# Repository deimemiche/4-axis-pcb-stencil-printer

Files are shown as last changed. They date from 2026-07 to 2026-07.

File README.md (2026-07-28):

# 4 Axis PCB Stencil Printer w/ Rotational Axis

Stencil printer shown from the top

This is a GitHub mirror/fork of the 4 Axis PCB Stencil Printer
with Rotational Axis by Philipp of [Dengler Mechatronik GmbH](https://dengler-mechatronik.de/).

You can find the source material on:
* [Thingiverse](https://www.thingiverse.com/thing:5690704)
* [Initial announcement](https://dengler-mechatronik.de/?p=560)
* [Digital build log](https://dengler-mechatronik.de/?p=790)

I chose to build this project because of its large working field,
and focus on what really matters - accurate stencil alignment.

All the modifications and their status is described below.

## Mods

### Top plate workholding
This mod adds workholding features (tapped holes) to the top plate,
making adding tooling a breaze.

Technical drawing: [`technical-drawings/top-plate-workholding.dxf`](`top-plate-workholding.dxf`)

Status: in use

### Linear Z axis
Caveat emptor: I never did manage to get the back of the eccenter Z axis working to my satisfaction.
The clamp either captured the threaded rod fully or not at all, not allowing for movement, or rendering
it in raspy freefall over the threads. It is possible I just didn't get it.

What I did manage to get working, however, is a Dremel against a left-over linear rod from a 3D printer,
and hence, the linear Z axis mod was born. It does away with the 2 x 140 mm long M8 threaded rods, and
replaces them with 2 x 140 mm long 8 mm linear rods riding on a bearing mounted to the top frame.
The eccenter mechanism is replaced with the same eccenter used on the front. In order to do that, the 2040
300 mm extrusion is swapped with a 2020 size extrusion of the same length.

Linear Z axis modification, showing linear rods and their mounting

Status: in use

### Hinge locks
The hinges I used still allowed for some play between the back of the frame and the moving part.
Hence the hinge locks were born: if you're looking for repeatability across multiple applies,
or just to increase overall rigidity of the top frame when closed, this is the drop-in addon to print. 

Status: in use

### Bottom plate access holes
This mod replicates the 10 mm access hole seen in the bottom plate in all of five bolt locations.
It allows for easier maintenance and mounting of the threaded rod driven axis as a whole.

Status: in use

## Structure

* [`technical-drawings/`](technical-drawings/) - technical drawings in DXF and PDF formats for CNC manufacturing
* [`cad/`](cad/) - source CAD files, either original author's (STLs), or mine (FreeCAD, CadQuery)
* [`cad/freecad/`](cad/freecad/) - the original author's STLs rebuilt as editable FreeCAD parts, with the tools that measure and check them
* [`docs/`](docs/) - documentation

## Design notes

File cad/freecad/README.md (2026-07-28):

# Parametric reconstructions of the original author's parts

The original author published the printed parts as STL meshes only, so there is
nothing to edit: no sketches, no dimensions, no history. This directory rebuilds
them as FreeCAD **PartDesign** bodies driven by fully constrained sketches, so
any dimension can be changed by double clicking a sketch and typing a new
number.

Each part is a Python script that draws the body, and the `.FCStd` it produces.
The script is the source; the `.FCStd` is a build artefact that is committed so
the parts can be opened without running anything.

## Layout

```
fcprim.py        the helper library every part script is written against
stlmeasure.py    measures the original meshes: layers, outlines, bores
build.py         rebuilds part scripts and reports which ones failed
verify.py        point-samples a built solid against the mesh it came from
stlrender.py     draws a mesh, so a shape can be looked at rather than guessed
export.py        tessellates a built body back to STL, to render against the
                 original

bot/             bottom frame, X and Y axes, rail and rod holders
eccf/            the front eccenter (README calls the mechanism the "eccenter")
sr/              the slewing ring - the rotary alpha axis
top/             top frame, stencil clamp, Z axis
misc/            parts belonging to no one assembly - feet, adapters
plate/           the plates and angles, drawn from the author's own 2D drawings
asm/             the machine itself: the parts put together with real joints
asm/render/      four views of each assembly, drawn by asm/render.py
```

`plate/` is the odd group out. Everything else here is reconstructed from an
STL, because that is all the author published of the printed parts -- but the
aluminium was drawn properly, and `../../technical-drawings/` has those
drawings. So those parts are *transcribed* rather than reverse engineered, and
their check is arithmetic on the drawing's own dimensions rather than a
comparison against a mesh. A mistyped hole position fails the build.

`asm/` is the assembly, built with the Assembly workbench so the machine is held
together by joints and can be driven to any pose rather than frozen in one.
[`ASSEMBLY.md`](ASSEMBLY.md) is the plan and the progress against it.

Every group holds `<part-name>.py` next to the `<PART_NAME>.FCStd` it builds,
named after the STL in [`../`](../) it was reconstructed from.

## Building

FreeCAD 1.1 is needed. With the flatpak:

```sh
alias fc='flatpak run --command=freecadcmd --filesystem=home org.freecad.FreeCAD'

fc cad/freecad/build.py                    # rebuild everything
fc cad/freecad/build.py eccf/eccf-bot.py   # rebuild one part
```

Run from the repository root. `build.py` exists because `freecadcmd` swallows
tracebacks - a script that raises simply prints nothing - so every build goes
through a wrapper that catches and prints them.

## Checking a reconstruction against the original

Two independent checks guard every part.

`build.py` compares the finished solid's volume against the mesh's. Agreement
to a few hundredths of a percent is the faceting error of the mesh's own curved
surfaces, and anything worse fails the build.

Matching volumes are good evidence but not proof, since material moved from one
place to another cancels out. That is not hypothetical: `ECCF_TOP`'s shoulders
were first drawn as plain rectangles because that is what a horizontal slice
through the middle of them looks like. They are really chamfered, and the
chamfer happens to have exactly the same volume as the rectangle - the build
check passed and the part was still wrong.

`verify.py` therefore classifies random points against both shapes -
`isInside` on the solid, ray casting on the mesh - and reports every
disagreement:

```sh
fc cad/freecad/verify.py cad/freecad/eccf/ECCF_BOT.FCStd cad/ECCF_BOT.stl
```

Points within 0.05 mm of a surface are excused, because there the mesh and the
true surface legitimately differ.

## Reading a mesh you want to reconstruct

`stlmeasure.py` runs under plain `python3` - no FreeCAD, no dependencies:

```sh
python3 cad/freecad/stlmeasure.py cad/BOT_RAIL_HOLDER.stl
python3 cad/freecad/stlmeasure.py cad/*.stl --summary
```

Measuring answers "what is there"; a picture answers "what is it". Arc fitting
cannot tell a fillet from a sweep from a draft, and a part whose outline is
nothing but tangent arcs is far quicker to read than to measure:

```sh
python3 cad/freecad/stlrender.py cad/ECCF_LEVER.stl          # four views
python3 cad/freecad/stlrender.py cad/A.stl cad/B.stl out.png # two, overlaid
```

Overlaying a reconstruction on its original is the quickest check there is that
a thread runs the right way round or a profile is not mirrored:

```sh
fc cad/freecad/export.py cad/freecad/sr/SR_WORM_GEAR.FCStd built.stl
python3 cad/freecad/stlrender.py cad/SR_WORM_GEAR.stl built.stl cmp.png
```

Printed parts are layered, so `stlmeasure.py` finds the axis a prism would
explain best,
finds the heights at which the cross section changes, and reports each layer's
outline with the arcs fitted back to centres and radii. It also lists every
cylindrical face about each axis, which is how cross drilled holes are found -
those never show up in the layers.

## Conventions

**Parts are modelled in their mesh's own coordinates.** Several of the STLs were
exported in assembly position rather than about a part origin - the ECCF and SR
groups stack around Y = 0 as they do in the machine. Keeping those coordinates
means the reconstruction can be compared to the mesh directly, and that the
assembly can place most parts without a transform.

**Y is up.** The original author's machine has Y vertical, so parts built along
their print axis are usually sketched on the XZ plane. Note that XZ pads towards
**-Y** while XY pads towards +Z and YZ towards +X; `fcprim.sketch` documents the
full mapping. A sketch normally sits on the part's top face with the pad running
down from it.

**Sketches come out fully constrained.** `fcprim.polyline` works out which
segments are horizontal or vertical, groups the coordinates those constraints
tie together, and adds exactly one dimension per remaining degree of freedom -
no redundancy, whatever mix of straight, slanted and arc segments a profile
uses. `build.py` warns about any sketch that ends up underdefined.

**A 45 degree break that adds material is a tapered pad, not a chamfer.**
`fcprim.pad` takes `taper=45.0`, which drafts the sides as the pad runs; draw
the profile at whichever end of the break is smaller. A `PartDesign::Chamfer`
can only take material away, and it also fails outright where the break has to
die out on a curved face. `STATUS.md` says which parts need which.

**A feature that fails is fatal.** `fcprim.finish` refuses to save if anything
came out `Invalid`, because FreeCAD's own behaviour is to report the throw to
the console, keep the last shape that worked, skip every later feature and hand
back a perfectly valid solid that is missing half the part.

**Constraints are named after what they drive**, so `leg_x1`, `bolt_y_u` and
`nut_across_corners` read sensibly in the Elements panel rather than appearing
as anonymous numbers.

## Notes on individual meshes

* `ECCF_LEVER.stl` contains **two separate shells** - it is a printing pair of
  two identical lever cheeks, not one part.
* `SR_WORM_GEAR.stl` is a helical gear. It is the one part a revolve cannot
  make, and `fcprim.helix` - `PartDesign::AdditiveHelix` - makes it from the
  same kind of fully constrained sketch as everything else.
* `TOP_CLAMP_BEARING_MOUNT_2.stl` is exactly `TOP_CLAMP_BEARING_MOUNT_1.stl`
  mirrored in Z, vertex for vertex. One part script covers both; the assembly
  mirrors it rather than a second body existing.

Several parts come in families, and finding the family is most of the work:

* `BOT_RAIL_HOLDER` and `TOP_RAIL_HOLDER` are the same collar drawn twice - a
  boss around the rail bore, a lobe around each bolt, a fillet rolling along the
  lobes' common tangent, a foot under each bolt. Only the bolt spacing differs,
  and that the bottom one's bore sits 1 mm off the bolt line.
* `BOT_ROD_HOLDER_ALPHA_AXIS`'s first 20 mm are
  `BOT_ROD_HOLDER_ALPHA_AXIS_SHORT` exactly; the rest is the barrel carrying on
  as a 1 degree cone.
* `TOP_CLAMP_SPANNER_CASE_1` and `_2` share an outline exactly.
* `TOP_CLAMP_NUT_HOLDER` and `TOP_CLAMP_SPANNER_COUNTER` share an X/Y footprint
  (X -11.4 .. 5, Y -14.8 .. 15.2) and the same side view - a spine, a block hung
  off it, and the gap between them - so the two run on the same rail.
* `BOT_BEARING_MOUNT_Y_AXIS_DRIVEN` and `BOT_RAIL_CLAMP_X_DRIVE` are hollowed
  from both faces over *identical* spans, with the same two hollow shapes. Once
  the first was drawn the second was mostly a matter of changing the eye's
  position.
* The three 8.2 mm rod clamps - `BOT_CLAMP_Z_AXIS`, `TOP_CLAMP_Z_AXIS` and
  `TOP_CLAMP_STOP` - are all a bore in a 16.2 mm boss with a saw cut and an M3
  pulling it shut.

All 39 meshes are rebuilt, and the 6 drawn parts alongside them, so `build.py`
comes back **45/45**. [`STATUS.md`](STATUS.md) carries the per-part table and
what each awkward one turned out to be; [`ASSEMBLY.md`](ASSEMBLY.md) is the plan
for putting them together into the machine, and how far it has got.

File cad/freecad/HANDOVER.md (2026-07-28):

# Handover: where the assembly stands, and what is wrong with it

Written at the end of a session that got the machine assembling and driving,
and then hit a contradiction it could not settle. This is the state to pick up
from. [`ASSEMBLY.md`](ASSEMBLY.md) is the plan and the reasoning;
[`STATUS.md`](STATUS.md) is the per-part record; this file is only "what is
broken and what was being done about it".

## Read this first: the live bug

**Two independent derivations of the alpha assembly's height disagree by about
5 mm, and the assembly cannot be right until that is settled.**

The alpha axis (the slewing ring and its two plates) rides the Y rails above
the print plate. How high it sits is the one number in `machine.py` that was
never derived, and two parts now claim different answers:

| from | says the plate's underside is at | how |
|---|---|---|
| `BOT_BEARING_MOUNT_Y_AXIS` | **Y = 15.2** | its flange top is 11.6 above its bearing bore, and the bore sits on the Y rail at Y = 3.6 |
| `BOT_RAIL_CLAMP_X_DRIVE` | **Y >= 20.15** | its arm tops out 16.55 above the rail it caps, and reaches *inboard*, under where the plate goes |

15.2 is below 20.15, so the plate would be driven through the cap's arm. One of
these readings is wrong.

### What is solid, and what is not

The **caps are almost certainly right**. `BOT_RAIL_CLAMP_Y_AXIS` is not a
standalone clamp at all -- it is the cap for `BOT_BEARING_MOUNT_X_AXIS`'s
trough, and everything agrees:

    mount cap bolts   x = +-9.0     cap bolts   z = +-9.0     same 18 mm
    mount trough      r = 4.05      cap groove  r = 4.05      same 8 mm rod
    mount house_z     +-10.5 (21)   cap length      21        cap sits on it
    mount width       27            cap width       27
    mount cap_nut_across = 5.7      manual buys 8 Square Nut M3

Four mounts, four caps (2 plain, plus `BOT_RAIL_CLAMP_X_DRIVE` and
`BOT_RAIL_CLAMP_Y_AXIS_1`), 8 x M3x10 = two each. That is manual step 7 exactly,
and `carriage.py`'s `check_caps` confirms each cap's groove lands on its
mount's trough.

So the doubt is on the **other** side. Things worth testing, roughly in order
of how likely they look:

1. **`BOT_BEARING_MOUNT_Y_AXIS` may not mount flange-up.** Its docstring says
   "bolted flat under the frame, with a 15.2 mm bearing seat hanging below it",
   which was written in an earlier session and may be a guess. If it hangs the
   other way the 11.6 becomes something else.
2. **The Y rails may not be at Y = 3.6.** That comes from
   `BOT_BEARING_MOUNT_X_AXIS`'s trough being 14.6 above its own bore, and the X
   rail being at Y = -11. Both are derived, but the X rail's -11 rests on the
   rail holder bolting into the *centre* slot of a 2020's inner face, which is
   assumption not measurement.
3. **The caps' arms may point outboard**, not inboard. That was tried in
   passing: it moves the arm to Z ~ +-144, which then fouls the frame's end
   members at Z = +-130..150. So probably not, but it was not tested properly.
4. **The X drive cap may belong on a different mount** from the one it was
   arbitrarily assigned to (`CAPS` in `carriage.py` assigns them in order).

## What is in the working tree but **not committed**

Last commit is `d21d723`. Everything below is uncommitted and only partly
verified -- decide whether to keep it before building on it.

| file | change | verified? |
|---|---|---|
| `bot/bot-rail-clamp-y-axis.py` | `ROD` + `BOLT1..2` datums | yes, builds, 0.018 % |
| `bot/bot-rail-clamp-y-axis-1.py` | same | yes, builds, 0.019 % |
| `bot/bot-rail-clamp-x-drive.py` | same | yes, builds, 0.018 % |
| `asm/carriage.py` | `rail_caps()`, `check_caps()`, `CAPS` | **yes** -- stage 3 passes |
| `asm/machine.py` | caps placed; `alpha_seat()` now derived from the carriage's own height instead of assumed | **no** |
| `asm/check.py` | new `placed()` helper | **no -- written, never run** |

### The last run, and why it failed

`machine.py` last completed with the alpha plate at **Y = 74.6**, which is
nonsense, and the slewing ring then clashed with the top frame's rails. That
number came from a **real bug that is fixed in the tree but never tested**:

> `App::Link` shares its shape with every other link to the same part, so
> `link.Shape.BoundBox` is the part where it was *drawn*, not where it was put.
> `alpha_seat()` was asking links for their bounding boxes directly and getting
> the wrong answer.

`check.placed()` was added to do this properly and `machine.py` now calls it.
**The very next thing to do is run `machine.py` and see what seat height it
gives.** It should be about 21.2 (the caps' top at 20.15 plus 1 mm). If it is,
the machine will assemble clash-free -- but it will still be sitting at a height
that contradicts `BOT_BEARING_MOUNT_Y_AXIS`, which is the bug above.

Note the same `.Shape` mistake may be lurking elsewhere; `check.solids()` always
handled links correctly, but anything else asking a link for geometry directly
is suspect.

## Everything else that is open

**Four parts exist nowhere** -- no STL, no drawing. Michael has said to leave
them for now:

    TOP_BRACKET   x8   step 12, top frame corners
    ECCB_BODY     x2   step 18, rear eccentric
    ECCB_LEVER    x2
    ECCB_SHIM     x2

**The worm drive is unplaced.** `ALPHA_BOT_PLATE` has a 10 mm hole at r = 75.45
but the ring's teeth are at r ~ 79, so the hole is not where a worm meshing
those teeth would sit. `BOT_ROD_HOLDER_ALPHA_AXIS` holds the worm shaft and its
geometry was never measured -- that is the evidence to go at next, and it should
settle the mesh radius directly.

**The Y bearing spacing is assumed.** `carriage.Y_BEARING_SPACING = 120.0` is a
guess, and it is what limits Y travel to +-25 mm. Closer together gives more.

**`TOP_CLAMP_Z_AXIS` does not verify clean** -- 2 mismatches in 20000 points,
reproducible, predating this work. See `STATUS.md`.

**Manual steps 8 and 9** (lead screws, springs, handwheels) are not built. The
two caps that carry the drives are now placed, which is the groundwork for them.

## What is done and working

All committed, all passing:

* 45 parts build (39 reconstructed from STLs, 6 drawn from the author's 2D
  drawings), `build.py` reports 45/45
* stages 0, 1, 2, 4, 5 and 7 pass; stage 3 passes including the caps
* the machine drives: X +-55, Y +-25, Z 66 mm, alpha +-32.6 deg, with
  interference re-checked at every step of the travel walk
* 32 fasteners placed from the parts' own `BOLT` datums, counts matching the
  manual
* exploded view and renders in `asm/render/`

## Running things

```sh
alias fc='flatpak run --command=freecadcmd --filesystem=home org.freecad.FreeCAD'

fc cad/freecad/build.py                 # all 45 parts
fc cad/freecad/asm/stage0.py            # the regression test for joints
fc cad/freecad/asm/frame.py             # stage 1
fc cad/freecad/asm/carriage.py          # stage 3
fc cad/freecad/asm/alpha.py             # stage 4
fc cad/freecad/asm/column.py            # stage 5
fc cad/freecad/asm/machine.py           # stage 7, the whole thing
fc cad/freecad/asm/render.py            # redraw everything
python3 cad/freecad/asm/reference.py    # fetch the author's step images
```

`machine.py` takes a few minutes -- the travel walk runs an interference pass
per step. `freecadcmd` prints **nothing at all** for an uncaught exception, so a
silent run means a crash, not success; `build.py` and `render.py` wrap
themselves to print tracebacks, and anything new should too.

Two flags worth knowing: `freecadcmd` swallows script arguments unless they come
after `--pass`, and it sets `__name__` to the module's basename rather than
`"__main__"`, which is why the stage scripts guard on `asmprim.is_entry()`.

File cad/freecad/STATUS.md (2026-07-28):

# Reconstruction status

## Mapping and gaps: mesh, model, manual

Three sets that ought to agree and do not quite: the STLs the author
published, the FreeCAD parts here, and the parts his assembly manual actually
calls for.

| | count |
|---|---|
| STLs in [`../`](../) | 39 |
| reconstructed from an STL | **39** -- every one, no orphans |
| FreeCAD parts with no STL | 6, the `plate/` group, drawn from his 2D drawings |
| **parts the manual needs that exist nowhere** | **4** |
| total parts built | 45 |

### The four that are missing

Nothing to reconstruct from and no drawing either, so these cannot be modelled
without either the author publishing them or somebody drawing them from
scratch:

| Part | Manual | Needed |
|---|---|---|
| `TOP_BRACKET` | step 12, top frame corners | x8 |
| `ECCB_BODY` | step 18, **rear** eccentric | x2 |
| `ECCB_LEVER` | step 18 | x2 |
| `ECCB_SHIM` | step 18 | x2 |

The front eccentric (`ECCF_*`) is published in full; the rear one is not. So
the machine can be assembled up to the top frame and no further. This is what
blocks stage 6, and half of what the top frame needs in stage 5.

### Names the manual and the meshes disagree on

Worth writing down, because each one looks like a missing part until it is
chased:

| the manual says | the mesh is called |
|---|---|
| `BOT_CLAMP_Z` | `BOT_CLAMP_Z_AXIS` |
| `BOT_TAIL_CLAMP_Y_AXIS_1` | `BOT_RAIL_CLAMP_Y_AXIS_1` (its typo) |
| `TOP_BEARING_MOUNT_1` / `_2` | `TOP_CLAMP_BEARING_MOUNT_1` / `_2` |
| `TOP_CLAMP_SPANNER_CASE` | `TOP_CLAMP_SPANNER_CASE_1` |
| `Adapter D5 to M3x14` | `ADAPTER_D5_TO_M3` |

### Assembly datums: 5 of 45

The gap that governs how much of the assembly is left. A part can only be
*joined* once it carries named datums (`fcprim.lcs`), and only the parts the
built stages actually join have them:

| Part | Datums |
|---|---|
| `BOT_RAIL_HOLDER` | `RAIL`, `MOUNT`, `BOLT1..2` |
| `BOT_BEARING_MOUNT_X_AXIS` | `RAIL`, `TROUGH`, `PLATE`, `BOLT1..4` |
| `BOT_CLAMP_Z_AXIS` | `ROD`, `MOUNT` |
| `TOP_CLAMP_Z_AXIS` | `ROD`, `MOUNT` |
| `TOP_RAIL_HOLDER` | `RAIL`, `MOUNT`, `BOLT1..2` |

The other 40 are reconstructed and checked but not yet joinable. That is by
design -- datums get added as the stage that needs them arrives, so they are
placed against a real mating requirement rather than guessed at.

### One inconsistency, harmless so far

`bot/bot-right-angle-con.py` builds through `fcprim.document` and
`fcprim.finish` directly instead of `fcprim.make`, so it skips
`check_sketches` and would not warn about an underdefined sketch. Checked by
hand: all four of its sketches are fully constrained, so nothing is hiding
behind it. Worth tidying, not worth hurrying.

## The parts that were drawn, not reverse engineered

The author published the aluminium as proper 2D drawings rather than as meshes,
so these six are transcribed from [`../../technical-drawings/`](../../technical-drawings/)
instead of measured off an STL. There is no mesh to compare against and none is
wanted: the check is that the finished solid's volume matches arithmetic on the
drawing's own dimensions, so a mistyped hole position fails the build.

| Part | Drawing | Size mm | Notes |
|---|---|---|---|
| `XY_PLATE` | `base-plate.dxf` | 257 x 162 x 2 | 16 x 3.2, at x +-97.65 / +-124.35, z +-59 / +-76 |
| `ALPHA_BOT_PLATE` | `bottom-plate.pdf` | 200 x 200 x 6 | 4 x M3 on a 122 bolt circle, 10 for the worm at x 75.45, 24 x M3 in clusters |
| `ALPHA_TOP_PLATE` | `top-plate-workholding.dxf` | 240 x 200 x 6 | 5 x M3 at r 75.45, plus an 83 hole staggered grid |
| `ALPHA_TOP_PLATE_PLAIN` | `top-plate-plain.dxf` | 240 x 200 x 6 | the same plate before the grid is drilled |
| `STENCIL_HOLDER_BOT` | `stencil-holder-bottom.pdf` | L 20x20x2, 198 | 4 x 5 at +-25 / +-75, one 5.4 through the upright |
| `STENCIL_HOLDER_TOP` | `stencil-holder-top.pdf` | L 20x20x2, 213.72 | 6 + 2 x 5, two 5.4; across-leg positions are the least certain thing here |

Two things fell out of doing these that were not obvious from the build page.
The alpha axis has **two** plates, a fixed 200 x 200 and a rotating 240 x 200,
which is why the page's "200 x 200 x 6" and the drawings' 240 x 200 looked like
a contradiction. And `ALPHA_TOP_PLATE`'s grid comes to exactly the 83 holes its
drawing annotates, which is a real check on having read the stagger right --
the script refuses to build if it does not.

## The reconstructed meshes

One row per mesh in [`../`](../). "Prismatic" is the fraction of the mesh's
surface area that a prism along the listed axis explains: 1.00 is a pure
extrusion, and the shortfall is chamfers, blends, cross drilled holes and
anything turned or helical. It is a fair proxy for how much work a part is.

Rebuilding a part means: measure it with `stlmeasure.py`, write the script,
then get both checks in [`README.md`](README.md) to pass - volume within the
mesh's own faceting error, and zero point classification mismatches.

**All 39 done.** Every script builds.

The claim that every one passes `verify.py` with **zero** mismatches does not
quite hold, and it is worth being exact rather than tidy about it.
`TOP_CLAMP_Z_AXIS` reports **2 mismatches out of 20000 sample points**, with 3
more excused inside the 0.05 mm skin. It is reproducible -- the sampler seeds
deterministically, so the same two points disagree every run -- and it is not
a regression: adding datums does not touch a body's shape, and the part's
volume reads the same before and after.

Two points in twenty thousand is a very small discrepancy, most likely one
detail of the saw cut or a break that is slightly off, and nothing built on
this part has shown it. But it is not zero, and the four other parts checked
alongside it (`BOT_RAIL_HOLDER`, `BOT_BEARING_MOUNT_X_AXIS`,
`BOT_CLAMP_Z_AXIS`, `TOP_RAIL_HOLDER`) do report a clean match, so the
difference is real rather than a quirk of the checker.

The remaining 34 have not been re-run recently -- `verify.py` takes a few
minutes a part -- so "all 39 pass" should be read as "all 39 passed when they
were written, and one of the five re-checked since does not". The worst volume deviation is 0.26 %, on `SR_WORM_GEAR`, and that is
the original mesh's own faceting error on a helical surface; the next worst is
0.054 %.

| Part | Size mm | Volume mm3 | Axis | Prismatic | Status |
|---|---|---|---|---|---|
| `ADAPTER_D5_TO_M3` | 6.4 x 3.5 x 6.4 | 52 | Y | 0.94 | **done** `misc/` |
| `BOT_BEARING_MOUNT_X_AXIS` | 27.0 x 26.2 x 35.0 | 10098 | X | 0.85 | **done** `bot/` |
| `BOT_BEARING_MOUNT_Y_AXIS` | 27.0 x 18.0 x 38.0 | 6369 | X | 0.94 | **done** `bot/` |
| `BOT_BEARING_MOUNT_Y_AXIS_DRIVEN` | 27.0 x 18.0 x 49.9 | 9014 | X | 0.96 | **done** `bot/` |
| `BOT_BRACKETS` | 60.0 x 4.0 x 60.0 | 8118 | Y | 1.00 | **done** `bot/` |
| `BOT_BRACKET_X_AXIS` | 36.0 x 19.8 x 60.0 | 9746 | X | 0.91 | **done** `bot/` |
| `BOT_CLAMP_Z_AXIS` | 31.8 x 40.0 x 17.2 | 10794 | Y | 0.86 | **done** `bot/` |
| `BOT_HANDWHEEL` | 30.0 x 26.0 x 29.4 | 10725 | Y | 0.81 | **done** `bot/` |
| `BOT_RAIL_CLAMP_X_DRIVE` | 43.9 x 16.5 x 27.0 | 8418 | Z | 0.83 | **done** `bot/` |
| `BOT_RAIL_CLAMP_Y_AXIS` | 21.0 x 7.0 x 27.0 | 3145 | X | 0.89 | **done** `bot/` |
| `BOT_RAIL_CLAMP_Y_AXIS_1` | 49.1 x 11.3 x 45.1 | 9094 | X | 0.83 | **done** `bot/` |
| `BOT_RAIL_HOLDER` | 11.4 x 16.0 x 28.6 | 2288 | X | 0.94 | **done** `bot/` |
| `BOT_RIGHT_ANGLE_CON` | 21.0 x 20.0 x 20.0 | 3861 | Z | 0.95 | **done** `bot/` |
| `BOT_ROD_HOLDER_ALPHA_AXIS` | 68.6 x 12.2 x 28.3 | 6310 | X | 0.62 | **done** `bot/` |
| `BOT_ROD_HOLDER_ALPHA_AXIS_SHORT` | 20.0 x 12.2 x 28.3 | 3204 | X | 0.93 | **done** `bot/` |
| `BOT_Z_AXIS_COUNTER_HOLDER` | 40.0 x 24.0 x 20.0 | 6349 | Y | 0.88 | **done** `bot/` |
| `BOT_Z_AXIS_COUNTER_KNOB` | 24.0 x 17.0 x 23.7 | 4762 | Y | 0.80 | **done** `bot/` |
| `ECCF_BOT` | 40.0 x 8.0 x 20.0 | 4961 | Y | 1.00 | **done** `eccf/` |
| `ECCF_HEIGHT` | 44.0 x 10.0 x 43.4 | 10162 | Y | 1.00 | **done** `eccf/` |
| `ECCF_LEVER` | 34.4 x 29.3 x 45.8 | 4929 | X | 0.74 | **done** `eccf/` |
| `ECCF_MOUNT` | 26.4 x 14.0 x 26.4 | 3888 | Y | 0.74 | **done** `eccf/` |
| `ECCF_TOP` | 44.0 x 27.0 x 26.4 | 13649 | Y | 0.89 | **done** `eccf/` |
| `SR_BEARING_PLATE` | 130.0 x 3.0 x 130.0 | 4887 | Y | 0.94 | **done** `sr/` |
| `SR_INNER_RING` | 140.0 x 10.0 x 140.0 | 12887 | Y | 0.63 | **done** `sr/` |
| `SR_OUTER_RING_W_GEAR` | 154.0 x 12.0 x 160.6 | 38024 | Y | 1.00 | **done** `sr/` |
| `SR_WORM_GEAR` | 10.0 x 20.0 x 10.0 | 754 | Y | 0.32 | **done** `sr/` |
| `STAND` | 11.5 x 7.0 x 11.5 | 373 | Y | 0.62 | **done** `misc/` |
| `TOP_CLAMP_BEARING_MOUNT_1` | 26.0 x 27.0 x 21.0 | 7142 | X | 0.94 | **done** `top/` |
| `TOP_CLAMP_BEARING_MOUNT_2` | 26.0 x 27.0 x 21.0 | 7142 | X | 0.94 | **done** `top/` |
| `TOP_CLAMP_NUT_HOLDER` | 16.4 x 30.0 x 14.0 | 4127 | Y | 0.90 | **done** `top/` |
| `TOP_CLAMP_SPANNER_CASE_1` | 3.2 x 14.0 x 58.0 | 1782 | X | 0.93 | **done** `top/` |
| `TOP_CLAMP_SPANNER_CASE_2` | 9.0 x 14.0 x 58.0 | 3572 | X | 0.96 | **done** `top/` |
| `TOP_CLAMP_SPANNER_COUNTER` | 16.4 x 30.0 x 58.0 | 19315 | Z | 0.94 | **done** `top/` |
| `TOP_CLAMP_SPANNER_HANDWHEEL` | 5.0 x 33.8 x 34.0 | 3111 | X | 0.99 | **done** `top/` |
| `TOP_CLAMP_STOP` | 10.0 x 20.8 x 15.6 | 1750 | X | 0.88 | **done** `top/` |
| `TOP_CLAMP_Z_AXIS` | 30.2 x 34.0 x 32.0 | 10387 | Y | 0.86 | **done** `top/` |
| `TOP_HANDWHEEL_Z_AXIS` | 38.0 x 17.0 x 37.5 | 11108 | Y | 0.91 | **done** `top/` |
| `TOP_RAIL_HOLDER` | 11.4 x 16.1 x 27.6 | 2166 | X | 0.91 | **done** `top/` |
| `TOP_SPRING_PLATE` | 19.4 x 4.4 x 19.4 | 769 | Y | 0.81 | **done** `top/` |

## The gusset that looked like a free-form blend

`BOT_RAIL_CLAMP_Y_AXIS_1` held out longest, and only because it was measured
the wrong way. Fitting arcs to its sections gave radii that changed with height,
which reads as a doubly curved surface and is exactly what a **torus** does: a
section of one is not a circle. Its outer surface is a 33.5 mm arc turned about
the tube's own axis, and two of the part's dimensions fall out of that arc
rather than being chosen - it reaches furthest out where the clamp block ends,
and it lands on the tube's own diameter where the part stops.

The flanks looked worse still: ruled, but neither plane, cylinder nor cone. They
are simply the two lines tangent to the tube **from the block's own front
corners**, rounded into those corners on 10 mm. Once that is seen the whole
gusset is one prism and one revolved cut.

The lesson is the same one `stlrender.py` teaches: measure a section and you get
numbers that fit many shapes; ask what construction would put a surface there
and usually only one answer survives.

## Shapes that turned up more than once

Recognising these cut the work on the second and third instance to almost
nothing, so they are worth looking for first.

* **Rail holders** (`BOT_RAIL_HOLDER`, `TOP_RAIL_HOLDER`) are twins, and
  `BOT_ROD_HOLDER_ALPHA_AXIS`'s first 20 mm are
  `BOT_ROD_HOLDER_ALPHA_AXIS_SHORT`.
* **`TOP_CLAMP_BEARING_MOUNT_2`** is exactly `..._1` mirrored in Z, vertex for
  vertex. `top-clamp-bearing-mount-2.py` runs the other script for its builder
  rather than repeating it.
* **The webbed arm.** `BOT_BEARING_MOUNT_Y_AXIS_DRIVEN` and
  `BOT_RAIL_CLAMP_X_DRIVE` are hollowed from both faces over *identical* spans -
  a 2 mm skin at each end and one 2 mm rib, at -13.5/-11.5, -9.5, 5.1/7.1,
  11.5/13.5. Both use the same two hollow shapes: a half round of radius 5.5
  about the eye between the ribs, and beside each skin the same idea drawn to a
  smaller radius and roofed with a 120 degree vee so it prints unsupported.
* **Knurled knobs** (`BOT_HANDWHEEL`, `BOT_Z_AXIS_COUNTER_KNOB`,
  `TOP_HANDWHEEL_Z_AXIS`, `ECCF_HEIGHT`) are all one turned section, one flute
  pocket and a polar pattern.
* **The 8.2 mm rod clamp** - bore 8.2 in a 16.2 boss, saw cut, M3 pulling it
  shut - is `BOT_CLAMP_Z_AXIS`, `TOP_CLAMP_Z_AXIS` and `TOP_CLAMP_STOP`.

## Look at the part

Everything here was measured before it was ever seen, and for prismatic parts
that is the better way round - an arc fitted to a section is worth more than a
picture. For the last few it was the wrong way round. `stlrender.py` draws a
mesh from four orthographic views; `ECCF_LEVER` had been sitting in the "hard,
organically blended" pile and turned out, on sight, to be a flat plate with an
eye at each end and a waisted arm between - an afternoon's guesswork replaced by
one glance.

It also checks work. `export.py` tessellates a built body back to STL, and
rendering the two together in different colours settles at a glance what a
volume figure cannot: whether a thread runs the right way round.

    python3 cad/freecad/stlrender.py cad/ECCF_LEVER.stl
    fc cad/freecad/export.py cad/freecad/sr/SR_WORM_GEAR.FCStd built.stl
    python3 cad/freecad/stlrender.py cad/SR_WORM_GEAR.stl built.stl cmp.png

## The one thing a revolve cannot do

`SR_WORM_GEAR` is a helix, and a helix advances along its axis as it turns.
`fcprim.helix` wraps `PartDesign::AdditiveHelix`, which sweeps a sketched
profile along one and wants exactly the same fully constrained sketch as
everything else - so the worm is a bored tube plus one trapezium, and not the
mesh it was assumed it would have to stay.

Two things about it are worth knowing. The thread starts and stops at the part's
own ends rather than running past them, so its first and last turn are only
partly there; running the sweep long and trimming instead puts 10 mm3 too much
material in. And `Mode` takes `"pitch-height-angle"` in lower case - the string
FreeCAD shows in the GUI is rejected.

## Chamfers that add material, and where dressups give up

A 45 degree break is a `PartDesign::Chamfer` only when it takes material away
from an edge that already exists. Two cases here are neither:

* **A break at the foot of a boss adds material** - `BOT_HANDWHEEL`'s lug is
  1 mm wider where it stands on the rim, and `BOT_CLAMP_Z_AXIS` stands on two
  ribs that flare out where they meet its underside. No dressup can do that.
* **A break that dies out on a curved surface** makes OCC fail outright:
  `BOT_HANDWHEEL`'s lug is broken 1 mm round its top, and that break runs out
  where the outline crosses the collar. `BRep_API: command not done`.

Both are drawn instead as a `Pad` with `taper=45.0`, which drafts the sides as
the pad runs. Draw the profile at whichever end of the break is *smaller* and
let the taper open it out. Where the tapered face must not appear on every side
of the profile - `BOT_CLAMP_Z_AXIS`'s ribs run the full width without a flare on
their ends - draw the trapezium in section and pad it the other way instead.

A dressup is still the right answer where the break follows something no single
sketch contains: both handwheels and the counter knob are broken 1 mm round the
rim, and that break follows the grip flutes as well, so it has to be taken after
the flutes are cut.

## A feature that fails is not an error

`fcprim.finish` now refuses to save if any feature came out `Invalid`. Without
that check a throwing feature is only reported to the console: the body keeps
the last shape that worked, **every later feature is silently skipped**, and the
result is still a valid solid. A failed chamfer on `BOT_HANDWHEEL` swallowed the
bore and two pockets after it and still built.

## Fillets that are surfaces, not extrusions

Where a boss stands on a plate, the fillet round its root runs along a curved
edge that no single sketch contains. `PartDesign::Fillet` is the obvious answer
and it does not work here: on `BOT_Z_AXIS_COUNTER_HOLDER` the boss also blends
into the plate's long edges tangentially, and a fillet that has to terminate on
a tangent surface junction fails outright - at any radius, one edge at a time or
all of them.

What does work is to draw the fillet in section, revolve it all the way round,
and pocket back the part of the ring that has no plate under it. Three sketched
features instead of one dressup, every dimension named, and nothing depends on
an edge number that moves when an earlier sketch changes.

Beware `Shape.BoundBox` after a revolve: it bounds the surfaces' control hulls,
not the solid, and read 0.9 mm too wide on that part. Point sampling said there
was nothing there, and there was not.

## Two ways the layer scan lies

Both cost an afternoon before they were understood, so they are worth stating
plainly. Neither shows up as a bad volume, which is why `verify.py` exists.

**A layer boundary is not always a real step.** `levels()` finds heights where
facets face along the build axis, and a cross drilled hole's cylinder has such
facets where it is tangent to the cutting plane. `BOT_ROD_HOLDER_ALPHA_AXIS_SHORT`
appears to have three layers and really has one: the two inner boundaries are
where its M3 holes turn over. `BOT_BEARING_MOUNT_X_AXIS` scans as a step at
X = +/-6.703 and that is only where its 3.6 mm bolt holes turn over. Worse, a
section taken through such a hole is cut into several loops that look like
separate bodies - `TOP_CLAMP_STOP` sections as three pieces at every height, and
is one.

**A real step does not always show up as a layer.** Anything sloped has no
facet facing along the axis at all. `TOP_CLAMP_STOP` scans as a clean prism
along X and its tongue has a 3 mm chamfer off both far corners;
`BOT_BRACKET_X_AXIS` scans the same way and its plate's inside corner is a
22.5 mm sweep. A prismatic score below about 0.95 means at least one such
surface is there to be found.

## When the volume is out, compare sections rather than guessing

Volume is one number and says nothing about where the material is. Slicing both
the mesh and the built solid at the same run of heights and differencing the
areas localises the error immediately, and the *shape* of the difference names
it: a constant offset is a missing prism, a smooth curve is a missing round.

`BOT_RAIL_CLAMP_X_DRIVE` was 13.8 % over. The section scan showed the error was
zero outside one span, so the outline and every hole were right; inside that
span the difference was a smooth symmetric curve, which turned out to be an
unmodelled tapered channel up the underside, plus a flat 32.9 mm2 that was a
half round drawn with its arcs bulging the wrong way.

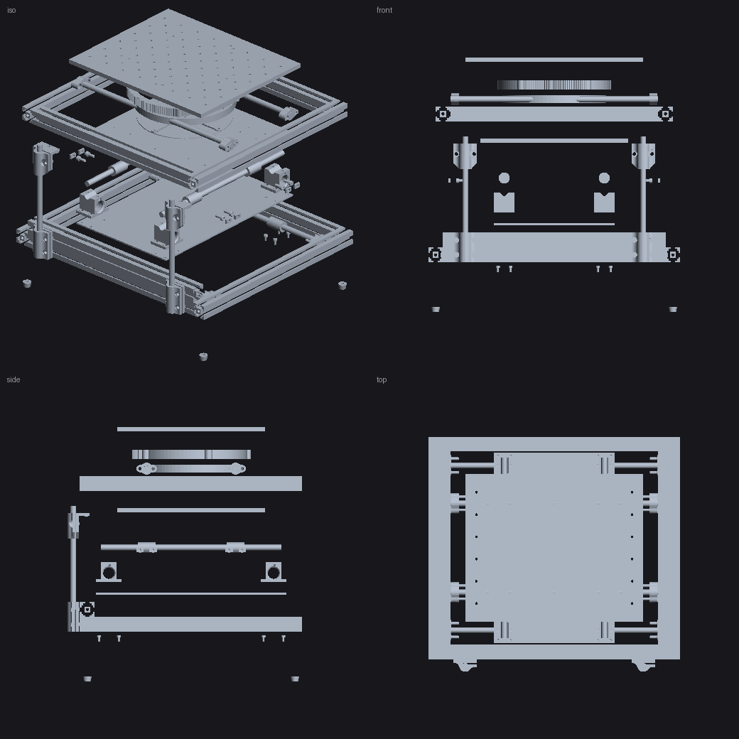
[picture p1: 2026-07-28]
cad/freecad/asm/render/MachineExploded.png

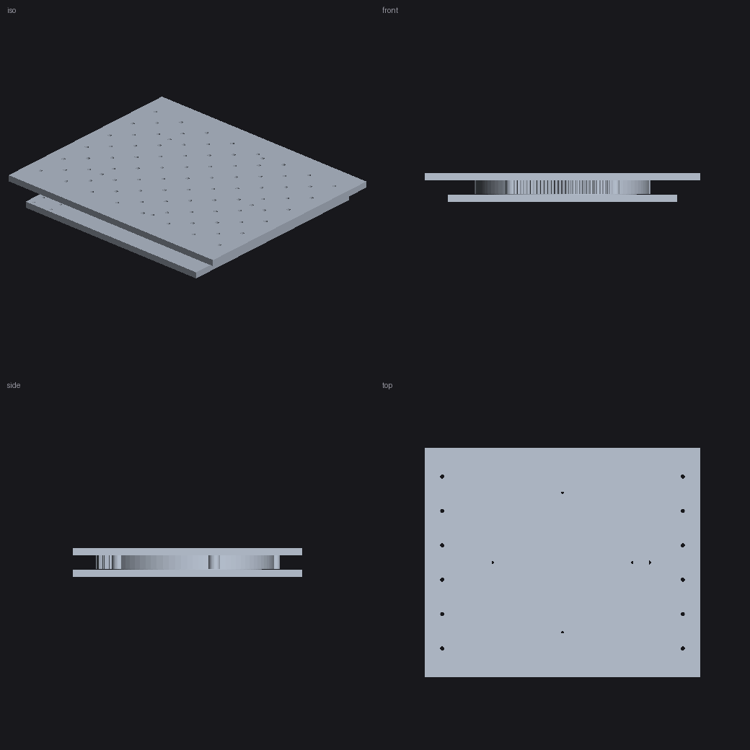
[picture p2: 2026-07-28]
cad/freecad/asm/render/Alpha.png

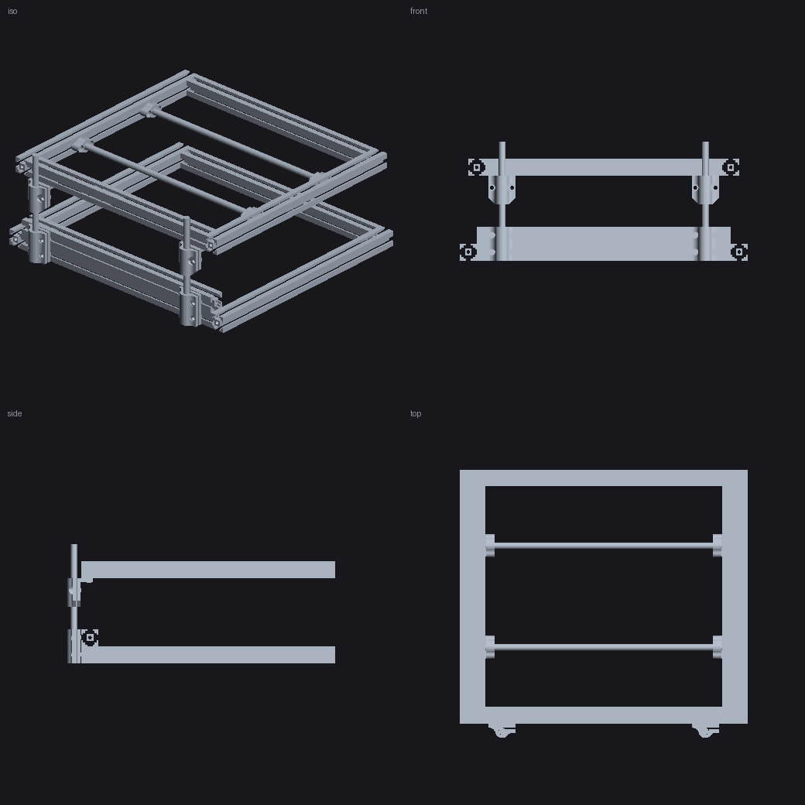
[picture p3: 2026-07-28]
cad/freecad/asm/render/Column.png

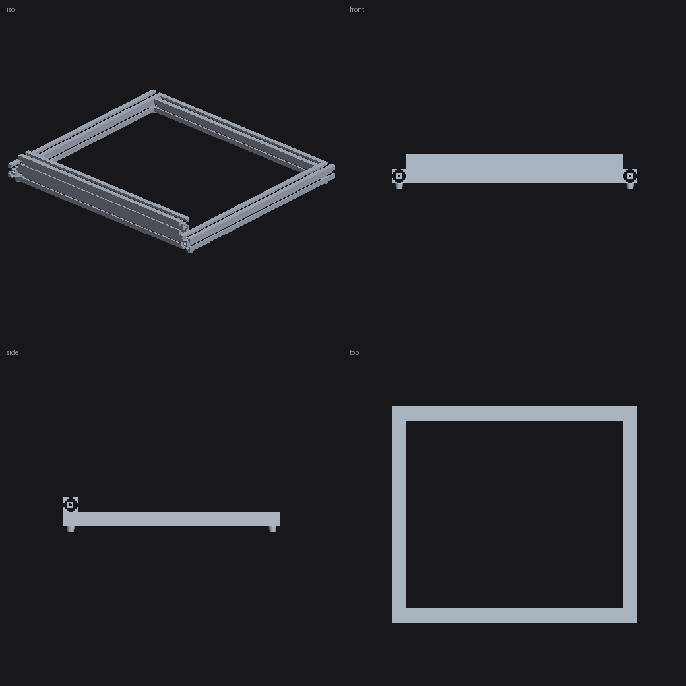
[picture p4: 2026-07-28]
cad/freecad/asm/render/BottomFrame.png

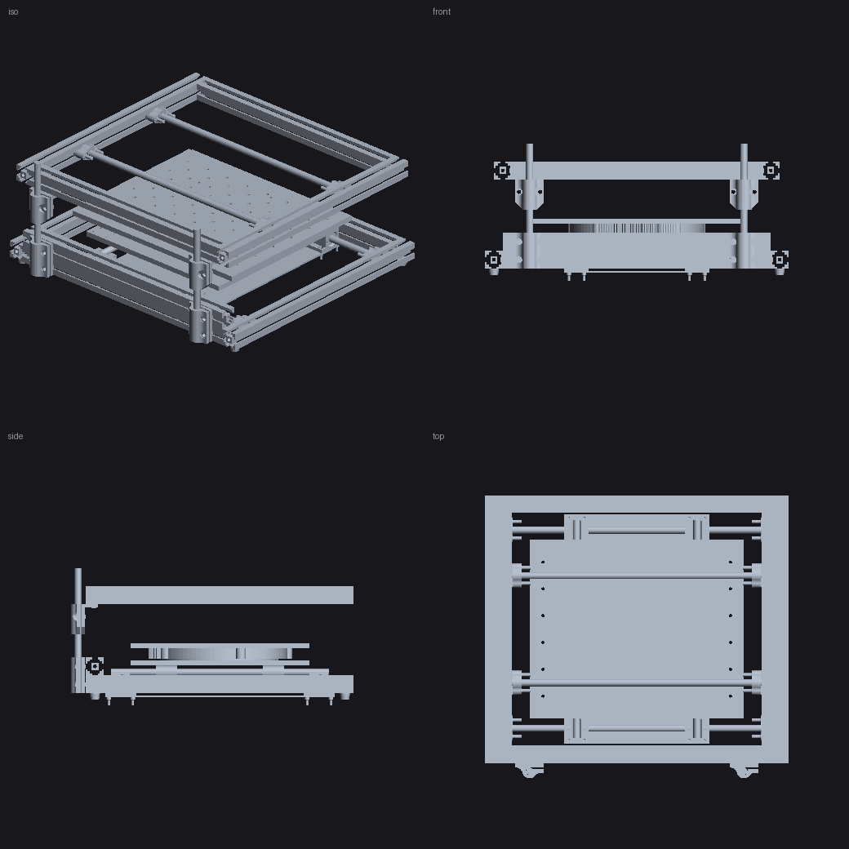
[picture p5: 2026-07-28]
cad/freecad/asm/render/Machine.png

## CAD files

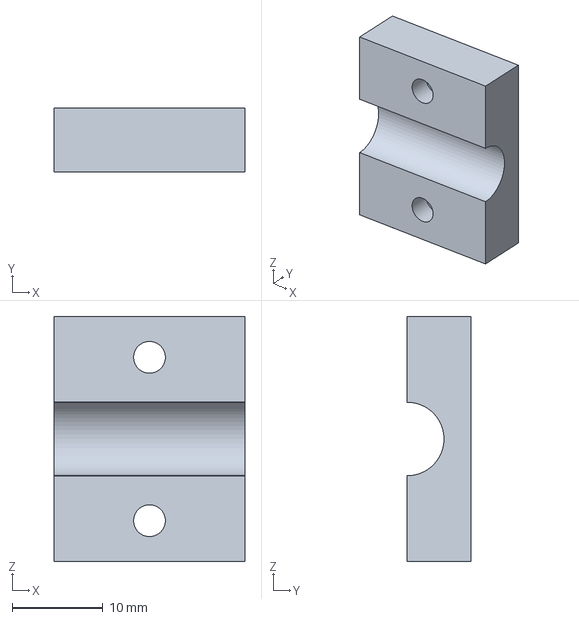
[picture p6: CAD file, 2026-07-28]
cad/freecad/bot/BOT_RAIL_CLAMP_Y_AXIS.FCStd
21.0 x 7.00 x 27.0 mm

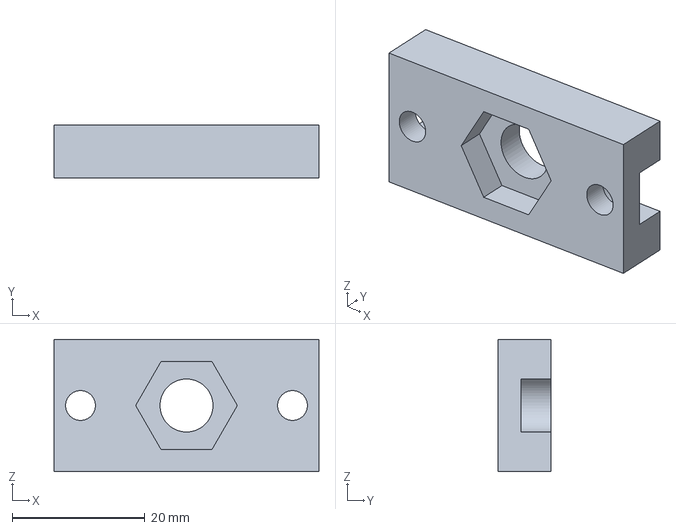
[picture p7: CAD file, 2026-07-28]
cad/freecad/eccf/ECCF_BOT.FCStd
40.0 x 8.00 x 20.0 mm

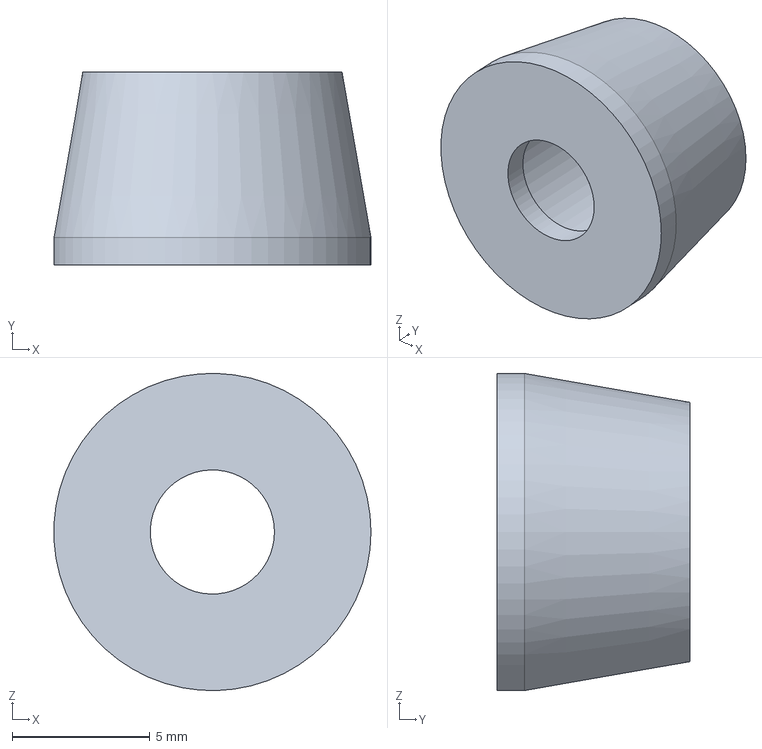
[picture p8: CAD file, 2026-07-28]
cad/freecad/misc/STAND.FCStd
11.5 x 7.00 x 11.5 mm

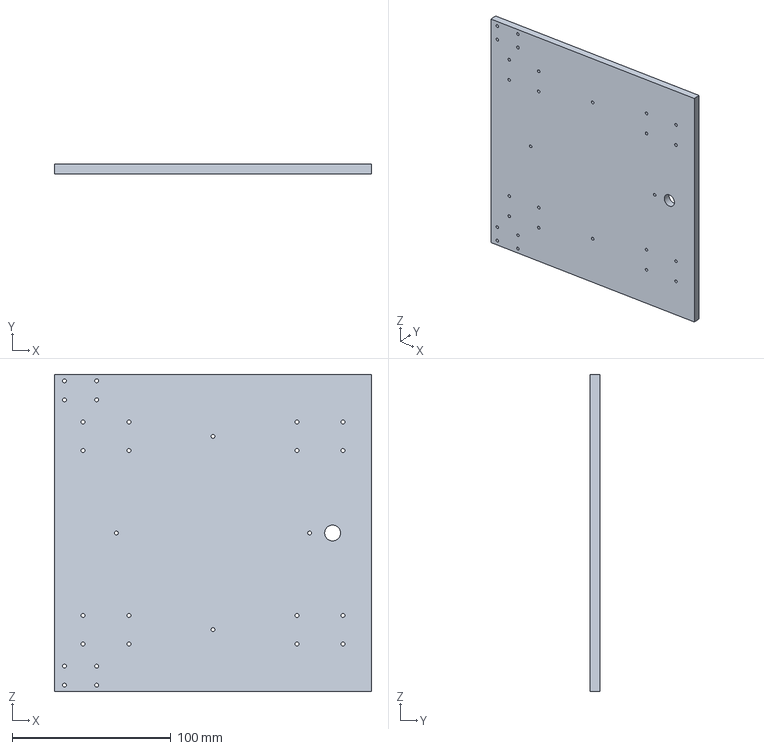
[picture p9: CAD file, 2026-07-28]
cad/freecad/plate/ALPHA_BOT_PLATE.FCStd
200.0 x 6.00 x 200.0 mm

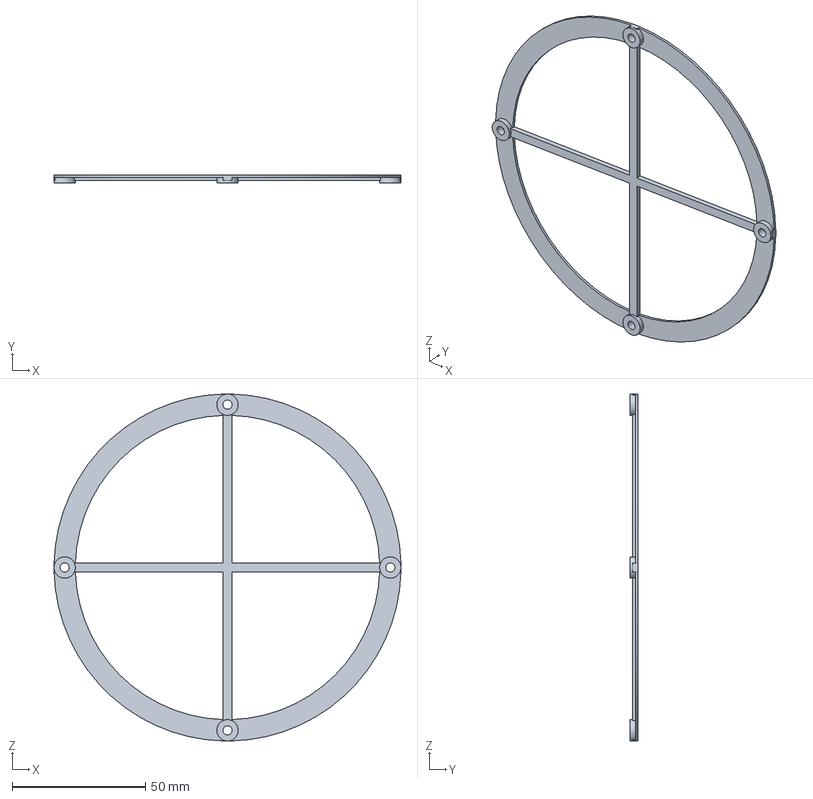
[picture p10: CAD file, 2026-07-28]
cad/freecad/sr/SR_BEARING_PLATE.FCStd
130.0 x 3.00 x 130.0 mm

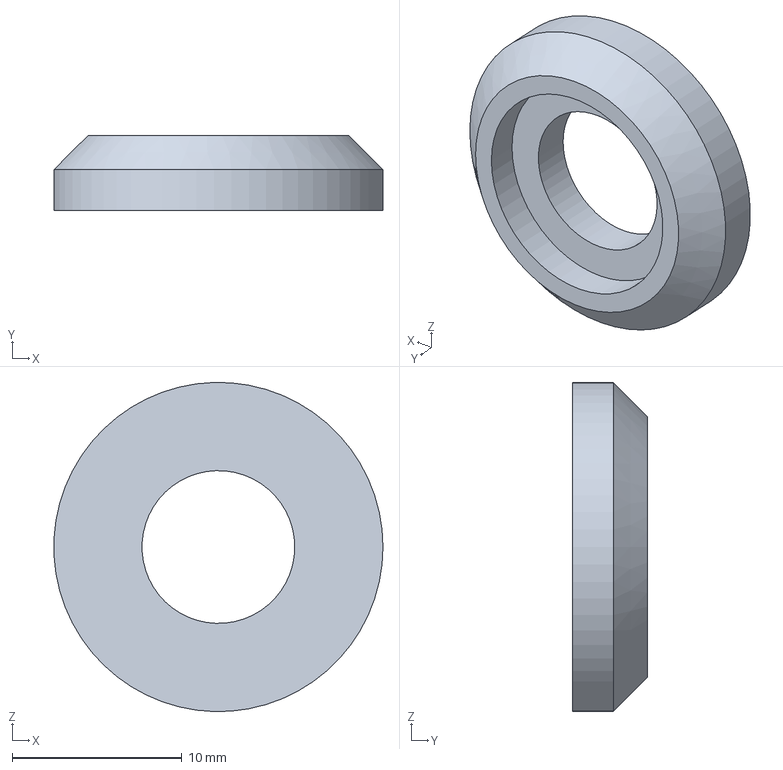
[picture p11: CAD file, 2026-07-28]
cad/freecad/top/TOP_SPRING_PLATE.FCStd
19.4 x 4.40 x 19.4 mm

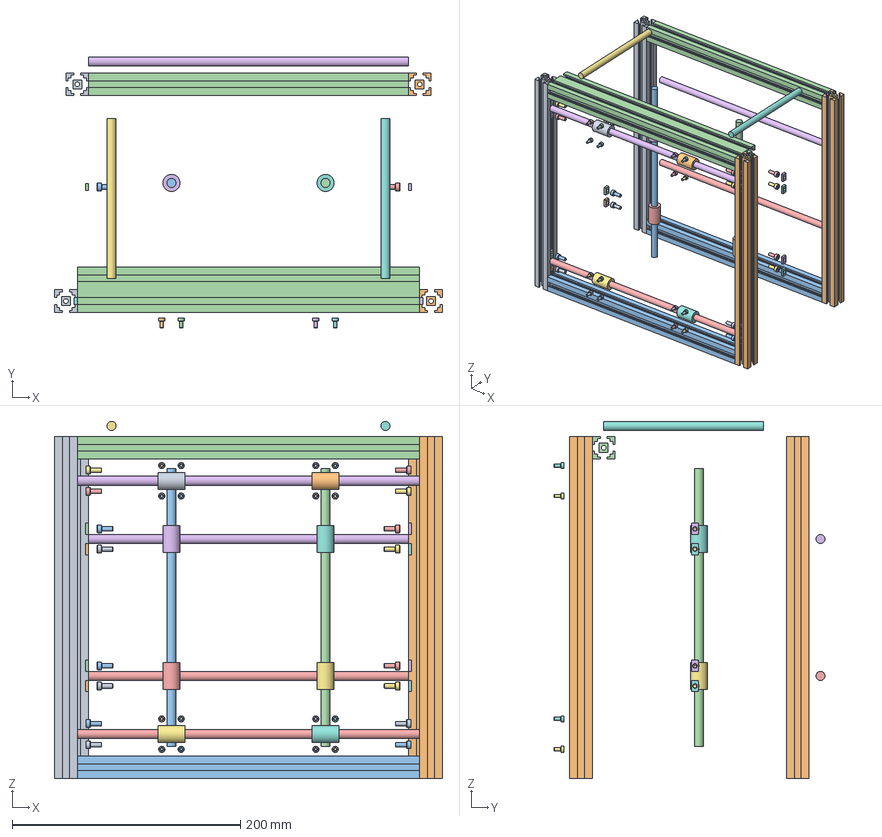
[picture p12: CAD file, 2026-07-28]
cad/freecad/asm/MachineExploded.FCStd
340.0 x 237.6 x 313.1 mm
2020 left
2020 right
2020 front
2040 back
X rail -111
X rail +111
LM8UU -68,-111
LM8UU +68,-111
LM8UU -68,+111
LM8UU +68,+111
Y rail -68
Y rail +68
LM8UU Y -68,-60
LM8UU Y -68,+60
LM8UU Y +68,-60
LM8UU Y +68,+60
top 2020 left
top 2020 right
top 2020 front
top 2020 back
top rail -60
top rail +60
M8x140 column -120
M8x140 column +120
M4x10 cap screw
M4 slot nut
M4x10 cap screw001
M4 slot nut001
M4x10 cap screw002
M4 slot nut002
M4x10 cap screw003
M4 slot nut003
M4x10 cap screw004
M4 slot nut004
M4x10 cap screw005
M4 slot nut005
M4x10 cap screw006
M4 slot nut006
M4x10 cap screw007
M4 slot nut007
M3x6 cap screw
M3x6 cap screw001
M3x6 cap screw002
M3x6 cap screw003
M3x6 cap screw004
M3x6 cap screw005
M3x6 cap screw006
M3x6 cap screw007
M3x6 cap screw008
M3x6 cap screw009
M3x6 cap screw010
M3x6 cap screw011
M3x6 cap screw012
M3x6 cap screw013
M3x6 cap screw014
M3x6 cap screw015
M4x10 cap screw008
M4 slot nut008
M4x10 cap screw009
M4 slot nut009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

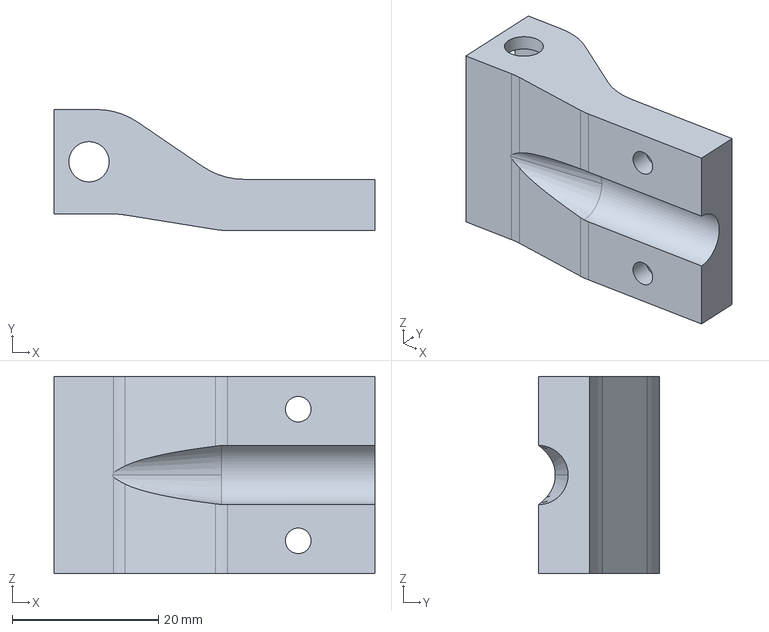
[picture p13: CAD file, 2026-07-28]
cad/freecad/bot/BOT_RAIL_CLAMP_X_DRIVE.FCStd
43.9 x 16.6 x 27.0 mm

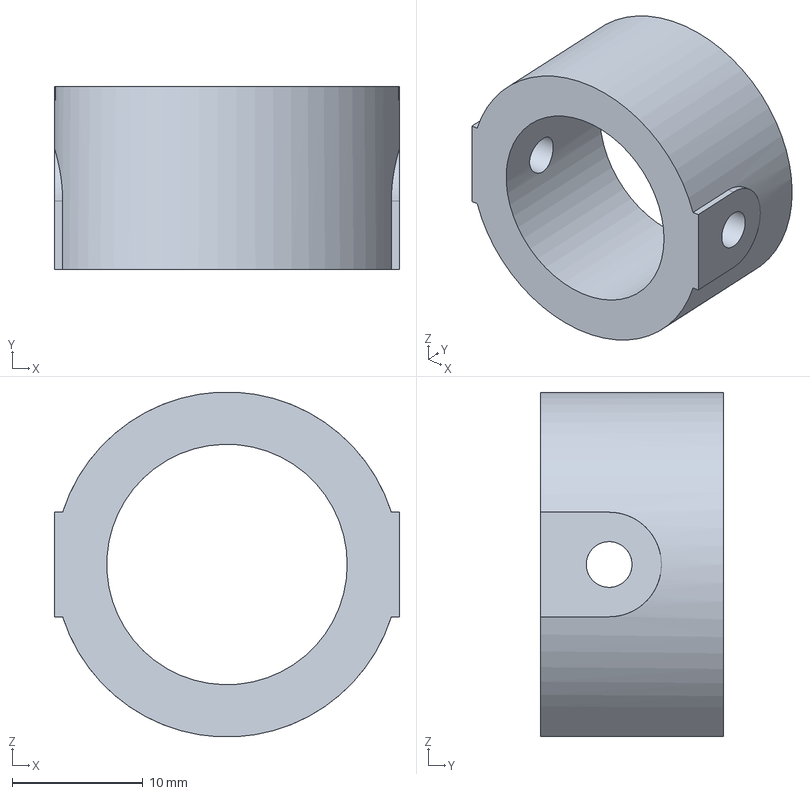
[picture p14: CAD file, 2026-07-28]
cad/freecad/eccf/ECCF_MOUNT.FCStd
26.4 x 14.0 x 26.4 mm

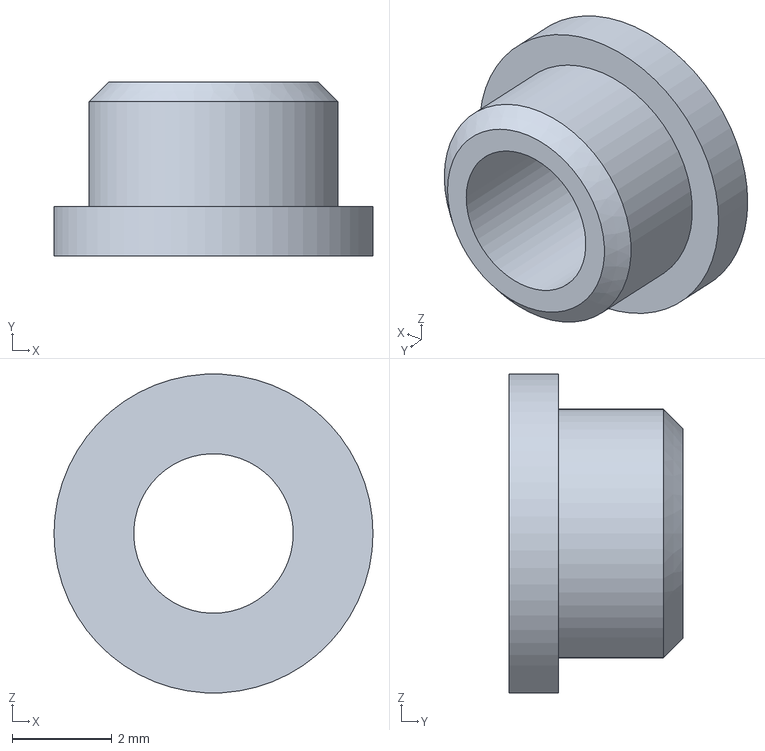
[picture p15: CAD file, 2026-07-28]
cad/freecad/misc/ADAPTER_D5_TO_M3.FCStd
6.40 x 3.50 x 6.39 mm

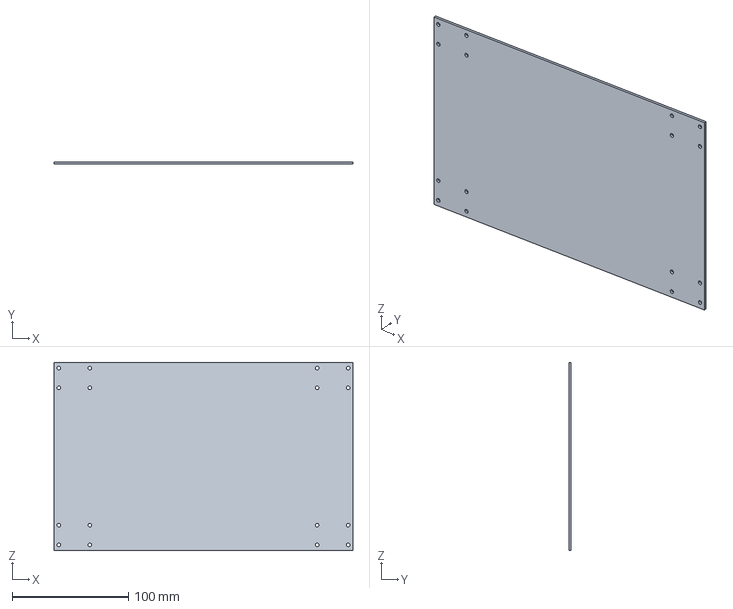
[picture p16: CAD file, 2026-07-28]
cad/freecad/plate/XY_PLATE.FCStd
257.0 x 2.00 x 162.0 mm

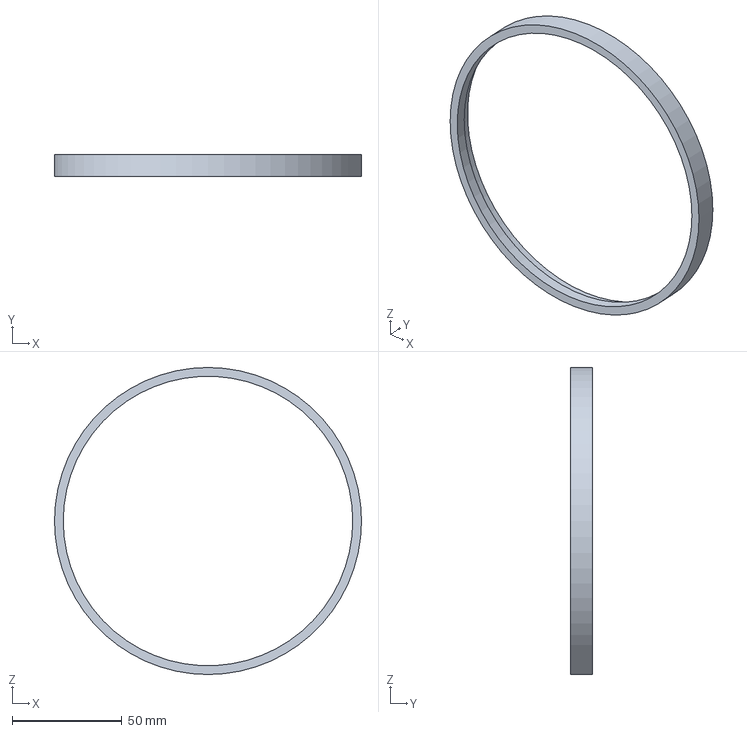
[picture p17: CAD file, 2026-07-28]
cad/freecad/sr/SR_INNER_RING.FCStd
140.0 x 10.0 x 140.0 mm

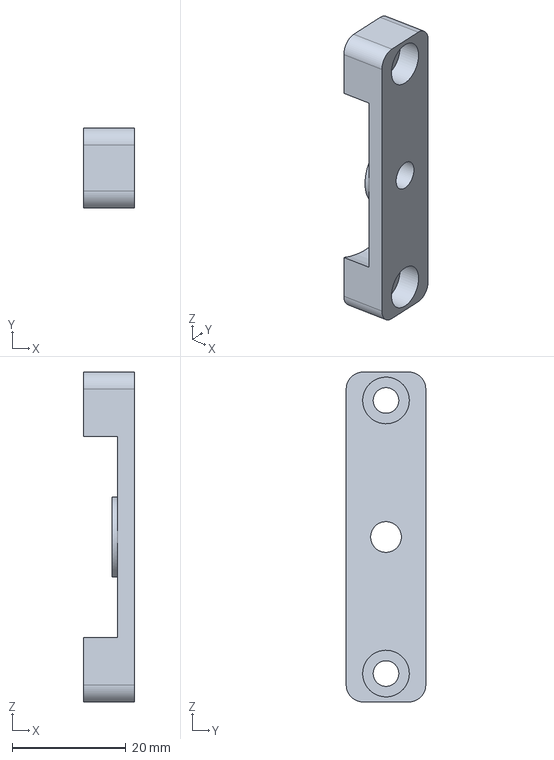
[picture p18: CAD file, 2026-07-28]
cad/freecad/top/TOP_CLAMP_SPANNER_CASE_2.FCStd
9.00 x 14.0 x 58.0 mm

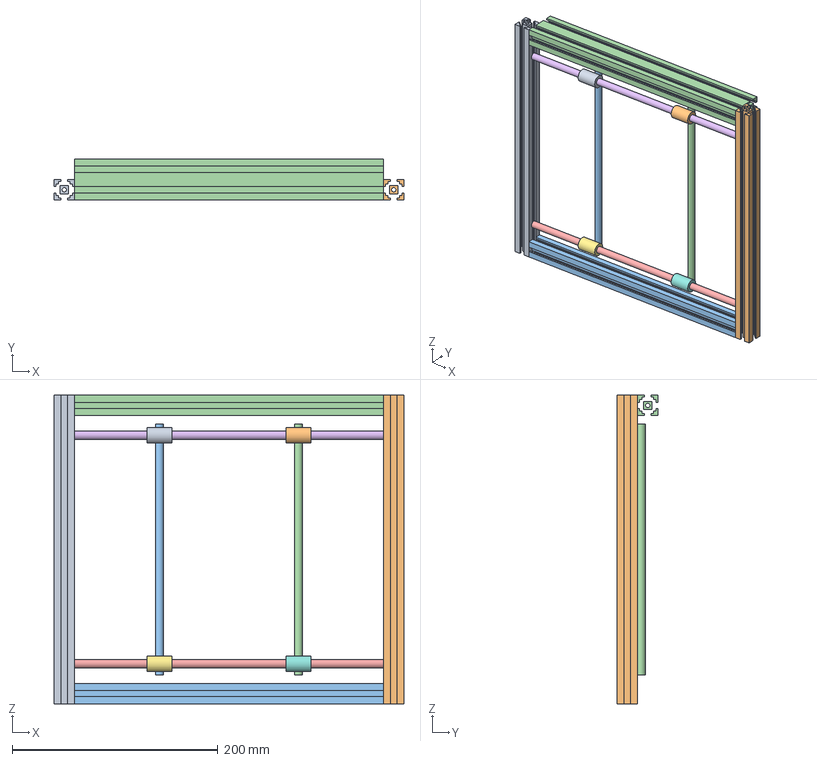
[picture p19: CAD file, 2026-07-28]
cad/freecad/asm/Carriage.FCStd
340.0 x 40.0 x 300.0 mm
2020 left
2020 right
2020 front
2040 back
X rail -111
X rail +111
LM8UU -68,-111
LM8UU +68,-111
LM8UU -68,+111
LM8UU +68,+111
Y rail -68
Y rail +68

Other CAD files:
cad/freecad/asm/Machine.FCStd
cad/freecad/bot/BOT_RAIL_CLAMP_Y_AXIS_1.FCStd
cad/freecad/eccf/ECCF_HEIGHT.FCStd
cad/freecad/plate/ALPHA_TOP_PLATE.FCStd
cad/freecad/asm/Alpha.FCStd
cad/freecad/asm/BottomFrame.FCStd
cad/freecad/asm/Column.FCStd
cad/freecad/bot/BOT_BEARING_MOUNT_X_AXIS.FCStd
cad/freecad/bot/BOT_BEARING_MOUNT_Y_AXIS.FCStd
cad/freecad/bot/BOT_BEARING_MOUNT_Y_AXIS_DRIVEN.FCStd
cad/freecad/bot/BOT_BRACKETS.FCStd
cad/freecad/bot/BOT_BRACKET_X_AXIS.FCStd
cad/freecad/bot/BOT_CLAMP_Z_AXIS.FCStd
cad/freecad/bot/BOT_HANDWHEEL.FCStd
cad/freecad/bot/BOT_RAIL_HOLDER.FCStd
cad/freecad/bot/BOT_RIGHT_ANGLE_CON.FCStd
cad/freecad/bot/BOT_ROD_HOLDER_ALPHA_AXIS.FCStd
cad/freecad/bot/BOT_ROD_HOLDER_ALPHA_AXIS_SHORT.FCStd
cad/freecad/bot/BOT_Z_AXIS_COUNTER_HOLDER.FCStd
cad/freecad/bot/BOT_Z_AXIS_COUNTER_KNOB.FCStd
cad/freecad/eccf/ECCF_LEVER.FCStd
cad/freecad/eccf/ECCF_TOP.FCStd
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

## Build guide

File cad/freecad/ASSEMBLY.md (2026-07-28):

# Plan: assembling the machine

The 39 printed parts are rebuilt and each one is checked against the mesh it
came from ([`STATUS.md`](STATUS.md)). This is the plan for putting them
together into a real FreeCAD assembly - one that is *correct*, that can be
rendered and exploded, and that can be extended later.

**Stages 0, 1, 2, 4, 5 and 7 are built, stage 3 as far as the XY carriage**, along
with the fasteners and the six parts the author drew in 2D. The Assembly
workbench works headless and joints can reference named datums, so the plan
below stands as written rather than falling back to scripted placements. What
is done, and what it found, is at the bottom under [Progress](#progress).

## What was decided

* **A full FreeCAD assembly**, not a picture. It has to hold up as the thing the
  machine is designed in from now on, so it must be correct, extensible, and
  usable for renders and an exploded view.
* **Stock parts are modelled too** - extrusions, rods, plates, bearings. The
  printed parts locate on them, so without them nothing is anchored.
* **Try the Assembly workbench's joints first.** Scripted placements are the
  fallback, not the starting point.

## The machine, from the build page

<https://dengler-mechatronik.de/?p=790>. The page is a full assembly manual:
eighteen steps, each with its own bill of materials. **Quantities re-read off
it and corrected** - the summary this table was first built from had two of
them loose:

| Group | Stock |
|---|---|
| Bottom frame | **1 x 2040 x 300** and **3 x 2020 x 300** extrusion, M4x10 DIN 912 + slot nuts, 4 printed stands |
| X / Y axes | 2 x 8 mm rod x 300 (X) and 2 x 8 mm rod x 244 (Y); 8 x LM8UU; aluminium plate 257 x 162 x 2; **2 x** M5 x 270 threaded rod, 2 handwheels, preload springs |
| Z axis | 2 x M8 x 140 threaded rod, printed clamps top and bottom |
| Alpha (rotary) | aluminium plate **200 x 200 x 6 (fixed) and 240 x 200 x 6 (rotating)**, **4 x** bearing 14 x 7 x 5, printed worm and ring gear, M5 threaded rod to a handwheel |
| Top frame | **3 x 2020 x 300** and **2 x 2020 x 280**, 2 hinges for 2020, linear rod, LM8UU, L profile, printed nut holders, stretcher |
| Eccentrics | 2 assemblies: M8 threaded rod, springs, printed levers, pressing the stencil onto the boards |

The three quantities the plan flagged as "worth double checking" all come out
right: **32 x M4x10**, **8 x LM8UU** and **4 stands** are exactly what step 1
and step 2 of the manual list. (An earlier pass through this file claimed the
32 was invented. That was wrong - it came from reading a summary of the page
rather than the page, and the manual gives it plainly.) The alpha plate is
*two* plates, which is why the 200 x 200 in the old table and the 240 x 200 in
the drawings looked like a contradiction and were not.

**The manual is a per-step bill of materials**, eighteen steps each listing
counts and part names, and it is the source for everything below. Reading it
properly settled both of the questions that were open, so it is worth saying
plainly: the answers were all in the manual, and the earlier passes had been
working from a summary of it.

The author's own CAD renders of each build step sit alongside those lists and
are the best reference there is for how it goes together. `asm/reference.py`
fetches them into `asm/reference/`, which is git-ignored - they are his images,
not ours.

### Four parts the manual needs and the repository does not have

Reading the step lists turned up parts that have no STL in [`../`](../), so
they were never reconstructed and the machine cannot be completed without them:

| Part | Where | Count |
|---|---|---|
| `TOP_BRACKET` | step 12, top frame | 8 |
| `ECCB_BODY` | step 18, rear eccentric | 2 |
| `ECCB_LEVER` | step 18 | 2 |
| `ECCB_SHIM` | step 18 | 2 |

`STATUS.md` says all 39 meshes are rebuilt and that is still true - but 39 is
not the whole machine. The front eccentric (`ECCF_*`) is published and the rear
one (`ECCB_*`) is not, and the top frame's own brackets are missing too. Stages
5 and 6 will reach them; there is nothing to reconstruct from, so they will
have to be drawn from the renders or left out and flagged.

Which printed part belongs where:

* **`bot/`** - frame brackets (`BOT_BRACKETS`, `BOT_BRACKET_X_AXIS`,
  `BOT_RIGHT_ANGLE_CON`), rod ends (`BOT_RAIL_HOLDER`,
  `BOT_ROD_HOLDER_ALPHA_AXIS`, `..._SHORT`), carriage
  (`BOT_RAIL_CLAMP_Y_AXIS`, `..._1`, `BOT_RAIL_CLAMP_X_DRIVE`), screw ends
  (`BOT_BEARING_MOUNT_X_AXIS`, `..._Y_AXIS`, `..._Y_AXIS_DRIVEN`), Z columns
  (`BOT_CLAMP_Z_AXIS`), drive (`BOT_HANDWHEEL`, `BOT_Z_AXIS_COUNTER_HOLDER`,
  `BOT_Z_AXIS_COUNTER_KNOB`).
* **`sr/`** - the alpha axis: `SR_BEARING_PLATE`, `SR_INNER_RING`,
  `SR_OUTER_RING_W_GEAR`, `SR_WORM_GEAR`.
* **`top/`** - Z columns (`TOP_CLAMP_Z_AXIS`, `TOP_HANDWHEEL_Z_AXIS`),
  `TOP_RAIL_HOLDER`, and the stencil clamp (bearing mounts 1 and 2, nut holder,
  spanner case 1 and 2, spanner counter, spanner handwheel, stop, spring plate).
* **`eccf/`** - `ECCF_BOT`, `ECCF_HEIGHT`, `ECCF_MOUNT`, `ECCF_TOP`,
  `ECCF_LEVER` (**two cheeks per eccentric**, and two eccentrics).
* **`misc/`** - `STAND` x 4, `ADAPTER_D5_TO_M3`.

## Datum

One machine origin, **Y up**, matching every part script. **Settled in stage 1**
and implemented in [`asm/frame.py`](asm/frame.py):

* **Y = 0 is the bottom frame's top face**, so a height reads directly as "how
  far above the frame".
* **X = 0, Z = 0 is the centre of the frame**, which runs -170 .. +170 across
  and -150 .. +150 along.  The frame reaches -190 .. +170 across, because the
  frame is 340 x 300 and centred on it.  Y = 0 is the top of the three 2020s;
  the 2040 at the back stands on edge and rises 20 mm above it, and the one
  plane all four members share is the **underside**, at Y = -20.

`stock.extrusion` puts a section's *top* at its own local Y = 0 rather than
centring it, so members of different heights hang from one common surface
instead of each needing an offset.

### What the pre-positioned groups actually say

The `ECCF_*` and `SR_*` meshes were exported in assembly position, and stage 1
reports rather than assumes where they land:

| | with an identity placement |
|---|---|
| `SR_OUTER_RING_W_GEAR` | Y -2 .. 10, centred on X = Z = 0 |
| `SR_INNER_RING` | Y -2 .. 8, centred |
| `SR_BEARING_PLATE` | Y 8 .. 11, centred |
| `ECCF_BOT` | Y -18 .. -10, centred on X |
| `ECCF_HEIGHT` | Y -10 .. 0 |
| `ECCF_MOUNT` | Y 0 .. 14 |
| `ECCF_TOP` | Y 0 .. 27 |

Both stacks are contiguous to the millimetre, so each group carries its own
**sub-assembly** datum and a good one: the three SR parts and the four ECCF
parts can be dropped in with an identity placement and will be right relative to
each other.

What neither carries is a *machine* datum. The alpha axis and the front
eccentric are each drawn about their own centre and nothing in the meshes
relates one to the other, so each group still has to be located as a unit. Worth
being explicit about, because "the parts are already in assembly position" is
true within a group and false between groups.

## How parts get joined

The risk with the Assembly workbench is that joints reference **named
topological subelements** - `Face12`, `Edge7`. Those names move the moment an
earlier sketch changes, which is exactly the fragility every part script here
avoids. Rebuild a part and the assembly quietly breaks.

So: **each part gains named mounting datums.** A `PartDesign::CoordinateSystem`
placed by the part's own script - on a bore axis, on a mounting face, on a bolt
circle - is parametric, survives a rebuild, and reads as what it is. Joints
reference those, never raw faces.

That is a change to `fcprim` and to the part scripts, and it is why stage 2
exists. It should add perhaps five lines to a typical part.

The joint types available in 1.1.3 cover the machine:

| Mechanism | Joint |
|---|---|
| Anything bolted solid | `Fixed` |
| Rod through a linear bearing or clamp bore | `Cylindrical`, or `Slider` once rotation is pinned |
| Lead screw driving a carriage | `Screw` (has a pitch) |
| Worm to ring gear | `Gears` (has a ratio) |
| Handwheels, the alpha axis | `Revolute` |

Pose then comes from the joints' own driving values, so the machine can be put
at any X / Y / Z / alpha position and re-checked, and an exploded view is an
offset applied along each joint rather than a second model.

## Fasteners: what FreeCAD actually has

Checked, rather than assumed: **FreeCAD 1.1.3 core ships no fastener library.**
The installed workbenches are AddonManager, Assembly, BIM, CAM, Draft, Fem,
Help, Idf, Import, Inspection, Material, Measure, Mesh, MeshPart, OpenSCAD,
Part, PartDesign, Plot, Points, ReverseEngineering, Robot, Show, Sketcher,
Spreadsheet, Start, Surface, TechDraw, Test, Web. No `Fasteners`, no
`PartsLibrary`.

Two ways to get them, and this is a decision for you:

1. **Fasteners Workbench** - an addon, one click in Tools > Addon Manager. It
   generates ISO/DIN screws, nuts and washers as real solids, is scriptable, and
   is what most people use. It would need installing (you install software
   yourself, so this one is yours to make).
2. **Draw them here** - a cap screw is a revolve plus a hexagon pocket, and
   `fcprim` already does both. Perhaps 60 lines for the M3 / M4 / M5 / M8 cap
   screws, nuts and washers this machine uses, fully parametric and with no
   dependency on an addon.

Recommendation: **(2)**, and treat the addon as optional. The machine uses a
handful of sizes in quantity, the parts would match the repository's style and
checks, and the assembly would not depend on an addon being installed to open.
Say the word if you would rather have the addon and I will use it instead.

Michael added: Fasteners workbench is now installed. Use it to follow the common norm.

**Settled: the addon.** It is installed and found, at

```
~/.var/app/org.freecad.FreeCAD/data/FreeCAD/v1-1/Mod/fasteners
```

so `asm/fasteners.py` will wrap it rather than drawing screws by hand, and the
sizes will be real DIN 912 / ISO geometry. The one thing to confirm when that
file is written is that it generates headless under `freecadcmd`, since parts of
the addon are written against the GUI; if it turns out to need one, drawing them
here is still the fallback and the wrapper's interface would not change.

## Files to be added

A tick is written and passing.

```
cad/freecad/
  fcprim.py            [x] gains `lcs()` - a named mounting datum on a body
  build.py             [x] knows about the new `plate/` group
  plate/               [x] the five parts the author drew in 2D, not printed
    xy-plate.py                XY_PLATE                257 x 162 x 2
    alpha-bot-plate.py         ALPHA_BOT_PLATE         200 x 200 x 6
    alpha-top-plate.py         ALPHA_TOP_PLATE         240 x 200 x 6, drilled
    alpha-top-plate-plain.py   ALPHA_TOP_PLATE_PLAIN   240 x 200 x 6, undrilled
    stencil-holder-bot.py      STENCIL_HOLDER_BOT      L 20x20x2, 198 long
    stencil-holder-top.py      STENCIL_HOLDER_TOP      L 20x20x2, 213.72 long
  asm/
    stage0.py          [x] the spike, kept as a regression test
    asmprim.py         [x] helpers: link a part, ground it, make a joint, solve
    stock.py           [x] extrusion, round rod, threaded rod, LM8UU, bearing,
                           spring
    frame.py           [x] the datum, the bottom frame, the four stands
    reference.py       [x] fetches the author's build-step renders
    render.py          [x] draws ours, and names his to compare against
    render/            [x] the drawings themselves -- committed, they are the
                           deliverable; the .stl beside each is regenerable
    fasteners.py       [x] cap screws, nuts, washers, via the addon
    carriage.py        [~] rails, holders, LM8UU, bearing mounts, the print
                           plate and the Y rails.  Still to come: the lead
                           screws, their preload springs and the handwheels
    alpha.py           [x] the slewing ring stack and both plates; the
                           worm drive goes with steps 7 to 9
    column.py          [x] the two Z columns and the top frame
    stencil.py         [!] stencil clamp, stretcher, eccentrics -- blocked,
                           see stage 6 below
    machine.py         [x] the whole machine, at a given pose
    check.py           [x] interference, alignment and fit checks
  ASSEMBLY.md          this file, kept up to date as it is built
```

`build.py` gains an `asm/` pass so the whole thing rebuilds with one command.

The plates are a **new part group rather than stock**, because unlike a rod
they have real drilled geometry that the assembly has to line up with. They are
built by `build.py` like every other part, and their volume check is arithmetic
on the drawing's own dimensions rather than a measurement of somebody's mesh -
so a mistyped hole position fails the build.

## Stages

Each stage ends with something that builds and checks, so progress is never a
half-finished document.

**Stage 0 - DONE.** Prove the Assembly API works headless:
create an assembly, link two parts, ground one, add one `Fixed` and one
`Cylindrical` joint, solve, save, reopen. Joints are Python features and may
want the GUI. *If this fails, we stop and reconsider* - the fallback is scripted
placements, which is known to work but gives up the kinematics. **Do this
first**, because everything else depends on the answer.

**Stage 1 - DONE.** `stock.py` and `asmprim.py`. Place the
extrusions and the four stands. Confirm the frame's overall size against the
published 300 mm profiles, and check where an identity-placed `SR_*` and
`ECCF_*` part lands.

**Stage 2 - mounting datums.** `fcprim.lcs()`, then add datums to the parts as
each is needed. Not all 39 up front - only what the current stage joins.

**Stage 3 - bottom frame.** Brackets, rod holders, the X and Y rods, LM8UU,
bearing mounts, lead screws, carriage clamps, the print plate. First real test:
are the four X-axis bores collinear?

**Stage 4 - alpha axis.** Bearing plate, inner and outer ring, worm on its
shaft, `Gears` joint to the ring, handwheel. The tooth pitch is already known
(2.25 degrees on the ring, 3.06986 mm axial on the worm), so the ratio is a
check, not a guess.

**Stage 5 - Z columns and top frame.** M8 rods, the four Z clamps, the top
extrusions, `TOP_RAIL_HOLDER`, the top handwheel.

**Stage 6 - stencil clamp and eccentrics.** The clamp train, the stretcher, two
eccentrics with two lever cheeks each.

**Stage 7 - the whole machine.** `machine.py` at a parametrised pose, the full
check pass, an exploded view, and renders. `stlrender.py` already draws
assembled STLs, so a render is nearly free.

## How it gets checked

The assembly is worth more as a test than as a picture: it is the first thing
that can catch an error in a part that its own volume and point checks cannot.

1. **Interference** - pairwise `common()` on every placed pair of solids. Any
   overlap above a small tolerance is a bug in a part or a placement. Clearance
   holes must be genuinely clear.
2. **Collinearity** - every bore that shares a rod must have a common axis. The
   four LM8UU on the X rod, the two rod holders, the clamps.
3. **Fit** - an 8 mm rod must pass every bore assigned to it; report the tightest
   clearance found, which also tells us the intended fits.
4. **Fastener alignment** - each screw hole must line up with the tapped hole or
   nut slot it drives, within tolerance. This exercises hole positions across
   part boundaries, which nothing has tested yet.
5. **Travel** - drive each axis to both ends and re-run interference, so the
   checks cover the machine's whole envelope rather than one pose.
6. **Overall size** against the published dimensions.

Michael added: Check also render pictures and compare them with existing pictures from the website manual.

## Risks, and what happens if they bite

* **Headless joints may not work.** Stage 0 exists to find out on day one.
  Fallback: scripted `App::Link` placements, adding joints in the GUI later.
* **Solver convergence.** Over-constrained assemblies fail unhelpfully. Build
  one joint at a time and solve after each, so the failing one is obvious.
* **The datum may not be what the parts imply.** Stage 1 tests it cheaply,
  before anything is built on top.
* **Missing information.** The build page gives stock sizes but not every
  position. Where it is silent, positions come from the parts' own mating
  features - which is the better source anyway, and is what the checks confirm.

## Open questions

1. **Fasteners** - the addon, or drawn here? (recommendation above: drawn here).
Michael: See comment above
**Resolved: the addon**, and it is installed. See the fasteners section.

2. **Are the published quantities right?** 32 x M4x10, 8 x LM8UU, 4 stands. They
   will be checked against the parts as each stage is built; a mismatch is worth
   knowing about either way.
Michael: Should be correct, but better double check.
**Checked against the page.** 8 x LM8UU and 4 stands are right. The 32 x M4x10
is not on the page at all, so it should not be trusted; the corrected stock
table above has what the page really says, including two things the old table
had wrong.

3. **The aluminium plates and L profiles** - the 257 x 162 print plate, the
   200 x 200 x 6 alpha plate, the stencil L profiles. Plain rectangles unless
   you have the real drilling patterns, in which case they are worth having.
Michael: In the "technical drawings" folder are 2D drawings of the plates and the L-profile. You may create also parts in Freecad of them first.
**Done - all five, with their real drilling.** See `plate/`. They are not plain
rectangles: the XY plate has sixteen 3.2 mm holes, the fixed alpha plate has a
122 mm bolt circle and 28 tapped holes, and the rotating one has an 83 hole
workholding grid.

### Settled, by reading the manual instead of guessing

Both of the questions that were open here are now closed, and neither needed
the hardware. They needed the manual's own step lists and a hard look at its
renders.

1. **How do the corners meet, and which way round is the 2040?**
   **Butt joints, and the 2040 stands on edge at the back.** Zoom the manual's STEP_1 render on a
   corner and an extrusion **end face** is there, T-slots and all, where a mitre
   would show a diagonal. Butt joints do not care how wide a member is, so the
   2040 can be 20 x 40 on edge, the four members line up underneath, and the
   four feet stand level. `check_level` had already argued for exactly this by
   failing.

2. **How long are the rails between their holders?**
   **The rail length *is* the span.** The top frame settles it without
   ambiguity: 2 x 2020 x **280** between two 300 mm members, and rails of
   8 x **280**. So a rail runs the full distance between the inner faces of the
   two members it bolts to. The bottom frame's X rails are 300, so its side
   members are 300 apart, so with a 20 mm member each side the frame is
   **340 x 300** - not the 300 x 300 square stage 1 first assumed, though every
   member is still 300 as the manual lists.

### Still open, and worth a glance from you

3. **`ALPHA_BOT_PLATE` is not symmetric.** The corner clusters of M3
   (x = -93.7 and -73.4) exist on the **left of the drawing only**; the inner
   clusters are on both sides. Read twice and it is still what the drawing
   shows, but it is unusual enough to be worth confirming.

4. **`STENCIL_HOLDER_TOP`'s across-the-leg hole positions.** That drawing
   dimensions from the inner face of the opposite leg, the opposite convention
   to the lower profile, and the two views show different legs at the same
   station. Lengthways (+-25, +-75, +-103.11) and the section are certain; the
   4.4 / 13.6 / 4.36 across-leg figures are my best reading.

## Progress

**Stage 0 - done.** [`asm/stage0.py`](asm/stage0.py), kept as a regression test
because a FreeCAD upgrade could take any of this back. What it establishes:

* the Assembly workbench drives fine from `freecadcmd`, no GUI;
* **a joint can reference a `PartDesign::CoordinateSystem`**, and the datum's
  own placement carries through into the assembly - so the plan's central bet
  holds and joints never have to name a face;
* `Fixed` moves a part to exactly the placement the joint implies, and
  `Cylindrical` puts a bore on its rod while leaving the slide and spin free -
  both checked numerically, not by eye;
* it survives save, close and reopen.

Three things about the API cost real time, all of them silent rather than loud,
and all three are now written down in `asmprim.py`'s docstring: a cross-document
link needs the owner document saved **first**; anything not grounded is fair
game for the solver to move instead of the part you meant; and `solve()` returns
**-1** on failure rather than raising, leaving every placement untouched, so an
unchecked call cannot be told apart from success. `asmprim.solve` raises.

**Stage 1 - done.** [`asm/frame.py`](asm/frame.py). The datum above, the four
mitred extrusions and the four stands, all grounded and solved. It checks its
own work: the frame comes out 300 x 300, centred, with its top face on Y = 0,
and the machine stands on Y = -47. A render of it against the author's STEP_1
agrees.

**Fasteners - done.** [`asm/fasteners.py`](asm/fasteners.py), wrapping the
addon: ISO 4762 cap screws (the current number for DIN 912), ISO 4032 nuts,
ISO 7089 washers, all real geometry and all generated headless. Two things had
to be found out the hard way and are written up in that file:

* importing the addon before `Part` is a **segmentation fault**, not an
  exception, so the import order there is deliberate;
* each fastener is **baked into a plain `Part::Feature`** and the addon's own
  `FeaturePython` thrown away, so the finished assembly can be opened by
  somebody who does not have the addon. That was the plan's original reason for
  preferring hand-drawn screws, and baking gets both halves of it.

The addon has no T-slot nut among its 307 types, so `slot_nut()` is drawn here.

**Stage 2 - done for the infrastructure.** `fcprim.lcs()` is written and proven,
and `BOT_RAIL_HOLDER` now carries the first real datums - `RAIL`, `MOUNT`,
`BOLT1`, `BOLT2` - which resolve correctly through `asmprim.at()`. Adding them
left the part's volume check untouched, which is the point: datums are inert.
The rest of the parts get theirs as the stage that joins them needs them.
## Stage 3 - the X axis

[`asm/carriage.py`](asm/carriage.py). Manual step 2. The four rail holders, the
two 300 mm rails and the four LM8UU that ride them, on the corrected 340 x 300
frame.

Measuring `BOT_RAIL_HOLDER` before placing anything is what made this tractable,
because its own geometry pins it down completely:

* **the rail bore and both bolt holes are parallel**, and the bolt heads
  counterbore from the far end - so the screws pull the collar flat against a
  face, and the rail leaves that face at right angles;
* **the two bolts are 18.583 mm apart**, not a multiple of 20, so they cannot
  be in two slots of a 20 mm profile. Both sit in **one** slot, which fixes the
  holder's orientation: its long axis along the slot, the rail out of the face;
* the bore sits **1 mm off the slot centre line**, which is the entire reason
  this part is not symmetric, and puts the rail at Y = -11.

Everything else follows from numbers already established, so nothing here is
placed by eye:

| | where it comes from |
|---|---|
| rails run X -150 .. +150 | the side members' inner faces, 300 apart |
| rails 222 apart, at Z = +-111 | the print plate's four hole clusters |
| bearings at X = +-67.5 | the same clusters; step 2's 16 M3x6 is 4 per mount |
| rail axis at Y = -11 | the 2020's slot centre line, less the holder's 1 mm |

The print plate is **162 across the rails and 257 along them**, not the other
way round: the Y rails are 244 and have to fit on it.

**The collinearity test passes** - the plan's first real test, and the first
thing the assembly can catch that no single part could. Each holder passes its
own volume and point checks and they could still fail to line up; both rails'
bore pairs come out parallel to 0.0 degrees and offset by 7e-14 mm.

Then the print plate, the four `BOT_BEARING_MOUNT_X_AXIS` that stand on it, and
the two Y rails clamped in their troughs.

**Which way round the plate goes was decided by its own bolt pattern**, not by
eye. The mount bolts down with four screws at 17 by 26.7 mm; the plate's holes
come in fours at 76 - 59 = **17** one way and 124.35 - 97.65 = **26.7** the
other. Only one orientation makes those meet, and it puts the plate's 257
across the rails and its 162 along them. Two things then fall out and both
check: each mount's outer face lands **flush with the plate's edge** at
Z = 128.5, and the 244 mm Y rails cross the 257 with 6.5 mm to spare each end.

**The fastener alignment check passes with zero error.** All sixteen mounting
bolts find a hole, the worst off by 0.000 mm. That is worth more than it
sounds: the plate comes from the author's **DXF drawing** and the mount from a
**reconstruction of his STL**, by different routes months apart in the original
work, and their hole patterns agree exactly. It is the first evidence either
one is right about anything beyond its own outline.

The mount is the corner of the XY stage and carries all three axes at right
angles, which fixes the whole stack once the bearing is on the rail:

| | Y |
|---|---|
| print plate, top face | -22.6 |
| X rail | -11 |
| Y rail, in the troughs | +3.6 |

So the plate hangs inside the frame's opening a little below its underside -
which is right for what it is, a carrier for the XY stage rather than a work
surface - and the Y rails run above the frame's top face, which is where the
alpha axis has to be since it rides them.

**Stage 3 is complete as far as the manual's step 2 goes.** The lead screws,
their preload springs and the handwheels are steps 7 to 9, and the manual does
them *after* the alpha axis - steps 3 to 6 build and fit that first, and the
drives are what finally tie the two together. Following its order rather than
the plan's guess, they come after stage 4.

## Stage 4 - the alpha axis

[`asm/alpha.py`](asm/alpha.py). Manual step 4.

### The SR group goes in upside down

This was the one thing stage 4 had to settle, and the parts settle it
themselves. In the meshes' own coordinates `SR_BEARING_PLATE` sits *above* the
rings - Y 8 .. 11 against the rings' -2 .. 10 - which would drive it straight
through the rotating plate. Turned over, everything lands at once:

| flipped | Y | |
|---|---|---|
| `SR_BEARING_PLATE` | -11 .. -8 | bolted flat to the fixed plate |
| `SR_INNER_RING` | -8 .. 2 | **seats on it exactly**, 0.0 mm |
| `SR_OUTER_RING_W_GEAR` | -10 .. 2 | **clears the fixed plate by 1 mm** |
| `ALPHA_TOP_PLATE` | 2 .. 8 | bolted to the outer ring |

Two things make that more than a coincidence of bounding boxes.

* **The ring that turns clears the fixed plate by exactly 1 mm, while the ring
  that does not seats on the bearing plate with exactly none.** A part that
  turns must not rub; a part that does not turn should be supported. The two
  rings differ by precisely the millimetre that needs - and only this way up.
* **Both of the manual's screw lengths come out right.** Step 3's **M3x8**
  passes the 3 mm bearing plate and bites 5 mm into the 6 mm fixed plate;
  step 4's **M3x14** passes the 6 mm top plate and bites 8 mm into the 12 mm
  outer ring. Neither works the other way up.

So the fixed side is bottom plate, bearing plate, inner ring; the turning side
is outer ring and top plate; and the worm drives the outer ring's teeth. The
whole axis stands 25 mm tall, which is the gap the manual's STEP_4 render shows
between its two plates.

### Both interfaces were exact before the stack was known

The two bolted interfaces cross the boundary between work done by completely
different routes - plates transcribed from the author's 2D drawings, rings
reconstructed from his STLs, months apart in the original effort:

| interface | drawing side | reconstruction side | agrees |
|---|---|---|---|
| fixed plate to bearing plate | `ALPHA_BOT_PLATE`, 4 holes | `SR_BEARING_PLATE`, 4 pads | r = **61.000**, 90 deg apart |
| turning plate to toothed ring | `ALPHA_TOP_PLATE`, 5 holes | `SR_OUTER_RING_W_GEAR`, 5 bosses | r = **75.450**, 72 deg apart |

With the sixteen carriage bolts in `carriage.py`, every mounting interface
tested so far agrees to the micron.

### The alpha axis does not go all the way round

`SR_OUTER_RING_W_GEAR` carries **29 teeth at 2.25 degrees**, and only over a
**72 degree sector** of the rim; the rest is plain. It is not a gear that turns
continuously, it is a sector that rocks, and the travel is about **+-32.6
degrees** - which is what a stencil wants: enough to square a board up, not
enough to spin it. 360 / 2.25 = **160** teeth for a complete rim, so a single
start worm gives 160:1 at the handwheel - the ratio the plan expected, arrived
at as a check rather than a guess.

**Still to place:** the worm and its M5 shaft, which belong with the lead
screws and handwheels of steps 7 to 9. `ALPHA_BOT_PLATE` has the 10 mm hole for
it at r = 75.45, so the mesh radius is already known.

## Stage 5 - the Z columns and the top frame

[`asm/column.py`](asm/column.py). Manual steps 10, 12 and 13.

**The top frame is where the frame rule came from**, so applying it back is not
circular: the rule was read off the top frame's own unambiguous arithmetic and
then *applied* to the bottom. Its rails are 280 and so are two of its
extrusions, so the two 300s are the sides, their inner faces are 280 apart, and
the frame is **320 x 300** - exactly one member narrower each side than the
bottom frame's 340 x 300, which is what lets it sit inboard of the columns.

Its two 280 mm rails come out collinear to 6e-14 mm, the same check the X rails
passed.

### How far the Z axis adjusts, and why

Step 18 says to "adjust the height of the top frame" without saying by how
much. The rod does: it is **M8 x 140**, `BOT_CLAMP_Z_AXIS` grips **40** of it
and `TOP_CLAMP_Z_AXIS` **34**, and the two cannot overlap, so

    140 - 40 - 34 = 66 mm of travel

`check_travel` reports it from the parts rather than asserting it, so a rebuild
that changed a clamp would change the answer. There is also a reach check:
the rod stands 19.1 mm outboard of the top frame's face and the top clamp is
30.2 mm wide, so it gets there.

### The two Z clamps mount completely differently

Worth recording, because assuming they were alike put both in the wrong place
until the interference check said so. `BOT_CLAMP_Z_AXIS` has its two M4 along
its own Z: it bolts flat to a **vertical face** with the rod standing off it,
and on the machine that face is the back 2040's outer face - whose 40 mm height
is exactly the clamp's own. `TOP_CLAMP_Z_AXIS`'s two M4 only pull its saw cut
shut; what holds it to the machine is a single bolt straight **up** through its
shelf into the top frame's underside.

Both now carry `ROD` and `MOUNT` datums and are placed from those rather than
by eye.

### What is left out, deliberately

* **The third 300 mm extrusion.** Step 12 lists three, and the STEP_12 render
  is plainly a four member rectangle. Step 16 then adds eight more screws and
  slot nuts, so the odd one is most likely the bar the stencil clamp hangs
  from - stage 6's business. Left out rather than guessed at.
* **The hinges and `TOP_BRACKET`.** The brackets are among the four parts with
  no STL in the repository, so there is nothing to place.
* **The columns' stations in plan.** Both Z clamps are on one side near its
  ends - the STEP_10 and STEP_12 renders agree, and the two hinges on that same
  side are what make it a lid. The exact stations along that side are read off
  the renders and are the least certain thing in this stage. Nothing else
  depends on them.

## Stage 7 - the whole machine

[`asm/machine.py`](asm/machine.py) and [`asm/check.py`](asm/check.py). Every
sub-assembly in one document at a given pose - X and Y along the rails, Z on
the columns, alpha on the ring - so the machine can be driven and re-checked
rather than frozen in one position.

**It stands up with nothing fouling.** 46 solids, 1035 pairs, 30 whose bounding
boxes touch at all, and no overlap above 1 mm3 once the pairs that are *meant*
to touch - a rod in its bearing, a clamp on what it holds - are excused.

    envelope 365.3 x 167.0 x 300.0 mm      X -195.3 .. 170.0
                                           Y  -27.0 .. 140.0  (up)
                                           Z -150.0 .. 150.0

### The interference check earned its keep immediately

It found the 2040 in the wrong place - twice, in the end, and each wrong answer
was ruled out by something real rather than by taste.

Stage 1 first had it **lying flat across the front**, from Z = -150 to -110.
The X rails sit at Z = +-111 and the print plate reaches +-128.5, so the
carriage ran straight through it. Nothing in stage 1, 3 or 5 could see that,
because each of them only ever looked at its own parts.

Moving it to a **side** cleared the carriage and passed every check - and was
still wrong, because it put the 2040 nowhere near the hinges. Michael caught
that one: the hinges mount to it, and they are on the **back**.

It is the **back member, standing on edge** - 20 mm across in plan like the
rest, 40 mm tall, with the four members flush underneath rather than on top so
it rises 20 mm proud. That upstand is what the hinges bolt to, it clears the
carriage because it is only 20 mm in plan, and the flush undersides are what
let all four feet be the same length. The frame is **340 x 300** and centred.

This is exactly what the plan expected the assembly to be worth: "the first
thing that can catch an error in a part that its own volume and point checks
cannot".

### The renders

[`asm/render.py`](asm/render.py) draws four orthographic views of each assembly
into [`render/`](render/) and prints which of the author's build-step images it
should be held against:

| ours | his |
|---|---|
| `render/BottomFrame.png` | STEP_1_1, STEP_1_2 |
| `render/Carriage.png` | STEP_2_2 |
| `render/Alpha.png` | STEP_4_2 |
| `render/Column.png` | STEP_10_1, STEP_12_1 |
| `render/Machine.png` | STEP_18_1 |

That is the half of the comparison a script can do - it makes ours and names
his. Deciding whether they agree still wants eyes. `reference.py` fetches his
into `reference/`, which stays git-ignored because they are his images; ours
are committed because they are the deliverable. The `.stl` beside each `.png`
is a by-product and is ignored.

`stlrender.py` was already in the repository and does the drawing with nothing
but Pillow, which the flatpak's own Python turns out to have - so this
tessellates and draws in one pass instead of shelling out.

### The machine actually drives now

X and Y were accepted in the pose and then ignored -- the header printed them
and nothing read them. They drive it now, and the travel is *measured* rather
than declared: each axis is walked outwards a step at a time until either two
parts touch or a bearing runs off the end of its rod.

| axis | travel | what stops it |
|---|---|---|
| X | **+-55 mm** | the bearing mounts reach the rail holders |
| Y | **+-25 mm** | the LM8UU run off the 244 mm Y rails |
| Z | **66 mm** | the M8 rod, less what the two clamps grip |
| alpha | **+-32.6 deg** | the ring's 29 teeth over a 72 degree sector |

So the work area is **110 x 50 mm**, and interference is re-checked at every
step of the walk, which is the plan's "drive each axis to both ends and re-run
interference".

Two things had to be got right for that to mean anything. An interference check
**cannot see a carriage running off the end of its rail** -- there is nothing
left to collide with -- so `check.on_its_rod` bounds the travel instead, and
the four LM8UU that carry the alpha axis along the Y rails had to be modelled
for it to have something to measure. That completes the manual's eight: four on
X, four on Y.

And the walk had to stop re-testing the whole machine at every step. Driving an
axis cannot change whether two *stationary* parts overlap, so `interference`
takes an `only` set and looks at pairs involving something that moved. Without
it the check does not finish.

### The fasteners are in

32 screws, placed from the parts' own `BOLT` datums rather than positioned a
second time -- so they land wherever the part says its holes are and cannot
disagree with it. The counts fall out of the datums and match the manual for
what is built: 8 x M4x10 into slot nuts for the bottom rail holders, 16 x M3x6
for the bearing mounts, 8 x M4x10 for the top ones.

The M3x6 is a small confirmation in itself. Those bolts come up from *under*
the print plate and into the mount's foot -- 2 mm plus 4 mm -- and the manual
buys exactly M3x6 for them.

### An exploded view

`explode()` lifts each layer clear of the one below in build order and saves
`MachineExploded.FCStd`; `render/MachineExploded.png` is the drawing. It is an
offset applied to the assembled machine, not a second model, which is the whole
reason for keeping it in one document at a known pose.

### The one number in it that is still soft

Where the alpha assembly sits on the Y rails. Manual step 6 says only "clip the
Alpha Axis Assembly to the LM8UU bearings", so its fixed plate rests directly
on top of them at Y = 11.1. Step 7's four `BOT_RAIL_CLAMP_*` are what actually
do the clipping and they are not modelled yet; whatever thickness they add,
they add here. The spacing of the two LM8UU along each Y rail is assumed at
120 mm, and that is what sets the +-25 mm of Y travel -- closer together would
give more.

## Stage 6 - not built, and why

The stencil clamp and the eccentrics are the one stage that cannot simply be
worked out, for two reasons that are worth separating.

* **Half the parts do not exist.** `ECCB_BODY`, `ECCB_LEVER` and `ECCB_SHIM` -
  the *rear* eccentric, step 18 - have no STL in the repository, nor does
  `TOP_BRACKET`. There is nothing to reconstruct from. The front eccentric
  (`ECCF_*`) is published and its four parts stack contiguously under an
  identity placement, so that half could be built.
* **Step 11 has no render.** Every other step in the manual has at least one
  CAD image; the front eccentric has none. So the one group whose parts *do*
  exist is also the one with no picture of how they go together.

The honest position is that stage 6 needs either the missing meshes from the
author or a decision to draw the rear eccentric from scratch, and that is a
choice for you rather than a gap to paper over.

**Next**, in the order the manual would do them: the lead screws, springs and
handwheels of steps 7 to 9, which finish stage 3 and also carry the worm that
drives the alpha ring; then whatever is decided about stage 6.

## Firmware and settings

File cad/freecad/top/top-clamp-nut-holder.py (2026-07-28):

"""TOP_CLAMP_NUT_HOLDER - carries the nut the stencil clamp's screw drives.

Reconstructed from the original author's TOP_CLAMP_NUT_HOLDER.stl, in that
mesh's own coordinates: 14 mm thick in Z, the screw running along Y.

Seen from the side it is a spine with a block hung off it, the gap between them
straddling whatever it slides on.  The spine's top ends in a 45 degree ramp, and
its foot spreads forward into an 8 mm barrel that runs out to both faces on
tangents - the only curve in the part.

An M3 drives the block, and its nut drops into a hexagonal seat open to the top
face, so it cannot turn.

Everything the part does not mate against is chamfered 1 mm on both faces: up the
block's front, over the ramp and down the spine's back.  It stops at the gap, the
foot and the block's underside.

    Body       sketch -> Pad      the whole side view, extruded across
    Base front sketch -> Pad      the barrel and its tangents, at the foot
    Edges              Chamfer    1 mm round the outside of both faces
    Screw      sketch -> Pocket   M3 clearance through the block
    Nut seat   sketch -> Pocket   its hexagon, and the slot it drops in through
"""

import math
import os
import sys

sys.path.insert(0, os.path.dirname(os.path.dirname(os.path.abspath(__file__))))

import fcprim

half_z = 7.0             # the part's thickness, either side of the screw
edge_break = 1.0         # the 45 degree break round both faces and the corners

spine_x = (-11.4, -8.4)
spine_y = (-14.8, 15.2)
ramp_at = 12.2           # the spine's top slopes back at 45 degrees from here

block_x = (-5.0, 5.0)
block_y = (-7.3, 12.2)

base_y = -11.8           # the foot spreads forward below this
barrel_d = 8.0
barrel_x = 1.0           # the barrel's axis, on the screw's line
run_out_r = 1.0          # where its tangents land on the faces

screw_hole_d = 3.5       # M3 clearance
screw_y = (-7.3, 0.2)
nut_across_flats = 5.7
nut_y = (-5.3, -2.7)

over = 2.0               # how far cutting profiles run past the part

mesh_volume = 4126.555


def broken(corner, towards, away, size):
    """The two points a 45 degree break puts where `corner` used to be."""
    def along(other):
        span = math.hypot(other[0] - corner[0], other[1] - corner[1])
        return (corner[0] + (other[0] - corner[0]) * size / span,
                corner[1] + (other[1] - corner[1]) * size / span)
    return [along(towards), along(away)]


def top_clamp_nut_holder(doc):
    bdy = fcprim.body(doc, "TOP_CLAMP_NUT_HOLDER")
    barrel_r = barrel_d / 2

    # Where the ramp meets the block's front face and the spine's top.
    ramp_low = (block_x[1], ramp_at - block_x[1])
    ramp_high = (ramp_at - spine_y[1], spine_y[1])

    # Drawn looking at the side; H is X, V is Y, and the pad runs across Z.
    # The foot is left at the spine's width here and spread forward afterwards.
    body = fcprim.sketch(bdy, "Body", "XY_Plane", offset=-half_z)
    fcprim.polyline(body, (
        broken((spine_x[0], spine_y[0]), (spine_x[0], spine_y[1]),
               (spine_x[1], spine_y[0]), edge_break)
        + [(spine_x[1], spine_y[0]), (spine_x[1], block_y[1]),
           (block_x[0], block_y[1])]
        + broken((block_x[0], block_y[0]), (block_x[0], block_y[1]),
                 (block_x[1], block_y[0]), edge_break)
        + broken((block_x[1], block_y[0]), (block_x[0], block_y[0]),
                 ramp_low, edge_break)
        + broken(ramp_low, (block_x[1], block_y[0]), ramp_high, edge_break)
        + broken(ramp_high, ramp_low, (spine_x[0], spine_y[1]), edge_break)
        + broken((spine_x[0], spine_y[1]), ramp_high,
                 (spine_x[0], spine_y[0]), edge_break)
    ), name="side")
    fcprim.pad(bdy, "Body", body, 2 * half_z)

    # The foot's front seen end on: the barrel, a 45 degree tangent off each
    # side of it, and a small radius where each tangent lands on a face.
    tangent = (barrel_x - barrel_r / math.sqrt(2), barrel_r / math.sqrt(2))
    run_out_x = (barrel_x - barrel_r * math.sqrt(2) + (half_z - run_out_r)
                 - run_out_r * math.sqrt(2))
    corner_x = barrel_x - barrel_r * math.sqrt(2) + half_z
    front = fcprim.sketch(bdy, "Base front", "XZ_Plane", offset=-base_y)
    fcprim.polyline(front, [
        (corner_x, -half_z),
        (tangent[0], -tangent[1]),
        (tangent[0], tangent[1]),
        (corner_x, half_z),
        (spine_x[0] + edge_break, half_z),
        (spine_x[0], half_z - edge_break),
        (spine_x[0], -half_z + edge_break),
        (spine_x[0] + edge_break, -half_z),
    ], name="front", arcs={1: -barrel_r},
        fillets={0: run_out_r, 3: run_out_r})
    fcprim.pad(bdy, "Base front", front, base_y - spine_y[0])

    # The foot's back corner is broken like every other, but the front pad has
    # just filled it back in, so it comes off again here.
    nick = fcprim.sketch(bdy, "Foot corner", "XY_Plane")
    starts, ends = broken((spine_x[0], spine_y[0]), (spine_x[0], spine_y[1]),
                          (spine_x[1], spine_y[0]), edge_break)
    fcprim.polyline(nick, [
        starts, ends,
        (ends[0], spine_y[0] - over),
        (spine_x[0] - over, spine_y[0] - over),
        (spine_x[0] - over, starts[1]),
    ], name="nick")
    fcprim.pocket(bdy, "Foot corner", nick, midplane=True)

    # The break runs right round the outside and stops wherever the part mates
    # with something: the gap it straddles, the foot, the block's underside.
    mates_at = (("x", spine_x[1]), ("x", block_x[0]), ("x", run_out_x),
                ("y", block_y[0]), ("y", block_y[1]),
                ("y", base_y), ("y", spine_y[0]))
    stays_sharp = ((spine_x[0], spine_y[0]), (block_x[0], block_y[0]),
                   (block_x[1], block_y[0]))

    def outside(edge):
        point = fcprim.midpoint(edge)
        if abs(abs(point.z) - half_z) > 1e-6:
            return False
        if any(abs({"x": point.x, "y": point.y}[axis] - value) < 1e-6
               for axis, value in mates_at):
            return False
        # The little breaks where the chamfer runs into a mating face stay put.
        return all(math.hypot(point.x - cx, point.y - cy) > edge_break
                   for cx, cy in stays_sharp)

    fcprim.chamfer(bdy, "Edges", edge_break, outside)

    screw = fcprim.sketch(bdy, "Screw", "XZ_Plane", offset=-screw_y[0])
    fcprim.circle(screw, (barrel_x, 0.0), screw_hole_d, name="screw")
    fcprim.pocket(bdy, "Screw clearance", screw, screw_y[1] - screw_y[0])
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

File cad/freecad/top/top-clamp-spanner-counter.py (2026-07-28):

"""TOP_CLAMP_SPANNER_COUNTER - the long rail the stencil clamp's spanner works against.

Reconstructed from the original author's TOP_CLAMP_SPANNER_COUNTER.stl, in that
mesh's own coordinates: 58 mm along Z, with the same side view as
TOP_CLAMP_NUT_HOLDER - a spine, a block hung off it, and a gap between them - so
the two run on the same thing.

An 8.4 mm slot up the middle of the block is where the spanner swings; its
bottom closes in a 120 degree vee so it prints unsupported.  The 5.6 mm screw
bore runs through the whole length underneath it.

Under the foot the front sweeps back to nothing at each end over an 8 mm nose.
An M3 comes up into the block at each end, and its nut slides in along a slot
that a 90 degree vee closes off.

    Body         sketch -> Pad      the side view, extruded the whole length
    Edges                Chamfer    1 mm round the outside of both end faces
    Nose         sketch -> Pocket   sweeps the foot's front back at each end
    Spanner slot sketch -> Pocket   what the spanner swings in
    Screw bore   sketch -> Pocket   5.6 mm through
    Bolts        sketch -> Pocket   two M3 up into the block
    Nut slots    sketch -> Pocket   their nuts, in from each end
"""

import math
import os
import sys

sys.path.insert(0, os.path.dirname(os.path.dirname(os.path.abspath(__file__))))

import fcprim

half_z = 29.0            # the whole length, either side of the middle
edge_break = 1.0

spine_x = (-11.4, -8.4)
spine_y = (-14.8, 15.2)
block_x = (-5.0, 5.0)
block_y = (-7.3, 15.2)
gap_top = 12.2           # the gap between spine and block closes here
base_y = -11.8           # the foot fills it in below this

nose_r = 4.0             # the foot's front sweeps back over this
nose_at = (1.0, 25.0)    # its centre, mirrored in Z
nose_ends = -3.2         # where the sweep has got to at the end face
nose_meets = 15.972      # where it leaves the foot's front face

screw_d = 5.6
slot_z = 4.2             # the spanner's slot, either side of the middle
slot_x = (-1.2, 3.0)
slot_root = -4.85        # where its 120 degree vee bottom closes

bolt_hole_d = 3.5        # M3 clearance, up into the nuts
bolt_z = 25.0
bolt_y = (-7.3, 0.2)

slot_across = 5.7        # the nut slot in from each end
slot_y = (-5.3, -2.7)
slot_apex = 20.5         # where its vee closes

over = 2.0               # how far cutting profiles run past the part

mesh_volume = 19314.972


def broken(corner, towards, away, size):
    """The two points a 45 degree break puts where `corner` used to be."""
    def along(other):
        span = math.hypot(other[0] - corner[0], other[1] - corner[1])
        return (corner[0] + (other[0] - corner[0]) * size / span,
                corner[1] + (other[1] - corner[1]) * size / span)
    return [along(towards), along(away)]


def tangent_from(point, centre, radius, hand):
    """Where a tangent drawn from `point` touches the circle."""
    span = math.hypot(point[0] - centre[0], point[1] - centre[1])
    angle = (math.atan2(point[1] - centre[1], point[0] - centre[0])
             + hand * math.acos(radius / span))
    return (centre[0] + radius * math.cos(angle),
            centre[1] + radius * math.sin(angle))


def top_clamp_spanner_counter(doc):
    bdy = fcprim.body(doc, "TOP_CLAMP_SPANNER_COUNTER")

    # Drawn looking at the side; H is X, V is Y, and the pad runs along Z.
    # The foot is left square here and swept back at the ends afterwards.
    body = fcprim.sketch(bdy, "Body", "XY_Plane", offset=-half_z)
    fcprim.polyline(body, (
        broken((spine_x[0], spine_y[0]), (spine_x[0], spine_y[1]),
               (block_x[1], spine_y[0]), edge_break)
        + broken((block_x[1], spine_y[0]), (spine_x[0], spine_y[0]),
                 (block_x[1], base_y), edge_break)
        + broken((block_x[1], base_y), (block_x[1], spine_y[0]),
                 (spine_x[1], base_y), edge_break)
        + [(spine_x[1], base_y), (spine_x[1], gap_top),
           (block_x[0], gap_top)]
        + broken((block_x[0], block_y[0]), (block_x[0], gap_top),
                 (block_x[1], block_y[0]), edge_break)
        + broken((block_x[1], block_y[0]), (block_x[0], block_y[0]),
                 (block_x[1], block_y[1]), edge_break)
        + broken((block_x[1], block_y[1]), (block_x[1], block_y[0]),
                 (spine_x[0], block_y[1]), edge_break)
        + broken((spine_x[0], spine_y[1]), (block_x[1], spine_y[1]),
                 (spine_x[0], spine_y[0]), edge_break)
    ), name="side")
    fcprim.pad(bdy, "Body", body, 2 * half_z)

    # Both end faces are broken 1 mm round the outside, stopping where the part
    # mates: the gap it straddles, the foot, the block's underside.
    mates_at = (("x", spine_x[1]), ("x", block_x[0]),
                ("y", block_y[0]), ("y", gap_top),
                ("y", base_y), ("y", spine_y[0]))
    stays_sharp = ((spine_x[0], spine_y[0]), (block_x[0], block_y[0]),
                   (block_x[1], block_y[0]), (block_x[1], spine_y[0]),
                   (block_x[1], base_y))

    def outside(edge):
        point = fcprim.midpoint(edge)
        if abs(abs(point.z) - half_z) > 1e-6:
            return False
        # Nothing in the foot: the nose sweeps all of it away at the ends, and
        # its front face is only as tall as the break itself.
        if point.y < base_y:
            return False
        if any(abs({"x": point.x, "y": point.y}[axis] - value) < 1e-6
               for axis, value in mates_at):
            return False
        return all(math.hypot(point.x - cx, point.y - cy) > edge_break
                   for cx, cy in stays_sharp)

    fcprim.chamfer(bdy, "Edges", edge_break, outside)

    # The nose: a tangent in from the end face, round the radius, and a tangent
    # back out to the foot's front.  Drawn looking down; H is X, V is Z.
    low = tangent_from((nose_ends, -half_z), (nose_at[0], -nose_at[1]),
                       nose_r, -1)
    high = tangent_from((block_x[1], -nose_meets), (nose_at[0], -nose_at[1]),
                        nose_r, 1)
    nose = fcprim.sketch(bdy, "Nose", "XZ_Plane", offset=-base_y)
    fcprim.polyline(nose, [
        (nose_ends, -half_z),
        low, high,
        (block_x[1], -nose_meets),
        (block_x[1], nose_meets),
        (high[0], -high[1]), (low[0], -low[1]),
        (nose_ends, half_z),
        (block_x[1] + over, half_z + over),
        (block_x[1] + over, -half_z - over),
    ], name="nose", arcs={1: -nose_r, 5: -nose_r})
    fcprim.pocket(bdy, "Nose", nose, base_y - spine_y[0], reversed_=True)
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

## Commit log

2026-07-28 Rebuild the author's 39 printed parts as editable FreeCAD models
    The original author published the printed parts as STL meshes only, so
    there was nothing to edit: no sketches, no dimensions, no history. Each
    part is now a PartDesign body driven by fully constrained sketches, so
    any dimension can be changed by editing a constraint.
    The script is the source and the .FCStd is a committed build artefact,
    so the parts open without running anything.
    Two independent checks guard every reconstruction, because either alone
    can pass on a part that is wrong:
    build.py compares the finished solid's volume with the mesh's, and
    fails on anything worse than the mesh's own faceting error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
    [ADAPTER_D5_TO_M3.FCStd, BOT_BEARING_MOUNT_X_AXIS.FCStd, BOT_BEARING_MOUNT_Y_AXIS.FCStd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]
2026-07-28 Add the six aluminium parts from the author's own 2D drawings
    Unlike the printed parts these were never published as meshes -- the
    author drew them properly, and technical-drawings/ has the DXFs and
    PDFs. So these are transcribed rather than reverse engineered, and
    their check is arithmetic on the drawing's own dimensions rather than a
    comparison against somebody's mesh. A mistyped hole position fails the
    build.
    XY_PLATE 257 x 162 x 2, 16 holes
    ALPHA_BOT_PLATE 200 x 200 x 6, fixed side of the alpha axis
    ALPHA_TOP_PLATE 240 x 200 x 6, with the 83 hole workholding grid
    ALPHA_TOP_PLATE_PLAIN the same plate before it is drilled
    STENCIL_HOLDER_BOT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
    [ALPHA_BOT_PLATE.FCStd, ALPHA_TOP_PLATE.FCStd, ALPHA_TOP_PLATE_PLAIN.FCStd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]
2026-07-28 Assemble the machine with real joints, and check it
    The parts are held together by Assembly workbench joints rather than
    hard-coded placements, so the machine can be driven to any pose and
    re-checked instead of being frozen in one.
    Joints reference named datums (fcprim.lcs) rather than face names. A
    joint that names Face12 breaks the moment an earlier sketch renumbers
    it -- the topological naming problem every part script here is written
    to avoid -- whereas a coordinate system placed by the part's own script
    survives a rebuild.
    Stages built: the datum and bottom frame, the XY carriage, the alpha
    axis, the Z columns and top frame, and the whole machine. stage0.py is
    kept as a regression t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
    [Alpha.FCStd, BottomFrame.FCStd, Carriage.FCStd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]
2026-07-28 Stand the 2040 on edge at the back, where the hinges mount
    The bottom frame's one 2040 was in the wrong place, and the two Z clamps
    with it.
    It is the **back** member, standing on edge: 20 mm across in plan like
    the other three and 40 mm tall, with all four members flush underneath
    rather than on top, so it rises 20 mm proud of the frame's top face.
    That upstand is what the top frame's hinges bolt to.
    Two earlier readings were wrong, and it is worth recording why each was
    ruled out. Lying flat across the front it would be 40 mm in plan,
    reaching Z = -150 to -110, and the X rails sit at Z = +-111 with the
    print plate at +-128.5 -- the whole-machine interference check found the
    carriage dri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
    [ADAPTER_D5_TO_M3.FCStd, ALPHA_BOT_PLATE.FCStd, ALPHA_TOP_PLATE.FCStd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]
2026-07-28 Make the machine drive, bolt it together, and explode it
    Three things were less finished than they looked, and this is the whole
    of what was outstanding except the four parts that do not exist.
    **X and Y did not drive.** The pose accepted them, printed them in the
    header, and never read them; only Z and alpha moved anything. They drive
    it now, and the travel is measured rather than declared -- each axis is
    walked outwards a step at a time until either two parts touch or a
    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
    [ADAPTER_D5_TO_M3.FCStd, ALPHA_BOT_PLATE.FCStd, ALPHA_TOP_PLATE.FCStd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]
2026-07-28 Correct the verify.py claim: TOP_CLAMP_Z_AXIS is not clean
    STATUS.md said every one of the 39 passes verify.py with zero
    mismatches. It does not. TOP_CLAMP_Z_AXIS reports 2 mismatches out of
    20000 sample points, with 3 more excused inside the 0.05 mm skin, and it
    is reproducible -- the sampler seeds deterministically, so the same two
    points disagree on every run.
    It is not a regression from adding datums: fcprim.lcs only adds a
    coordinate system to the body's group and never touches the feature
    chain, so the solid is unchanged, and the volume reads the same before
    and after. This predates the assembly work.
    Two points in twenty thousand is small, and nothing built on the part has
    shown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
2026-07-28 Add a handover: the alpha height contradiction, and an untested fix
    Stopping mid-problem, so this records the state rather than pretending
    it is finished.
    The live bug: two independent derivations of how high the alpha assembly
    sits disagree by about 5 mm. BOT_BEARING_MOUNT_Y_AXIS puts the plate's
    underside at Y = 15.2; BOT_RAIL_CLAMP_X_DRIVE's arm tops out at 20.15
    and reaches inboard under the same plate. One reading is wrong, and the
    caps are the better evidenced of the two -- every dimension of
    BOT_RAIL_CLAMP_Y_AXIS matches BOT_BEARING_MOUNT_X_AXIS's trough, so they
    are a cap-and-trough pair rather than a standalone clamp, which is
    manual step 7 exactly. So the doubt is on the Y bear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
    [BOT_RAIL_CLAMP_X_DRIVE.FCStd, BOT_RAIL_CLAMP_Y_AXIS.FCStd, BOT_RAIL_CLAMP_Y_AXIS_1.FCStd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]
